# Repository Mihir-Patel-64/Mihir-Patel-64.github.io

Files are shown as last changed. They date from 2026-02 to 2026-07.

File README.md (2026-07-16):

# R6 Recon Amphibot – Team XPED Documentation

This repository contains the technical documentation for the ESP32 Wireless Communication Gateway, my individual subsystem contribution to Team XPED's R6 Recon Amphibot, developed as part of EGR314 Embedded Systems Design.

The documentation covers the complete subsystem development process, including requirements definition, hardware architecture, component selection, power analysis, schematic and PCB design, firmware interfaces, API documentation, verification, and engineering reflections.

## Website

https://mihir-patel-64.github.io/

## My Responsibilities

- Designed the ESP32-S3 Wireless Communication Gateway
- Implemented the MQTT ↔ UART communication bridge
- Developed Wi-Fi connectivity and failsafe behavior
- Implemented the camera streaming infrastructure
- Designed the hardware and PCB layout
- Documented firmware architecture and APIs

## Repository Contents

- Requirements
- Hardware Architecture
- Component Selection
- Schematic and PCB Design
- Firmware API Documentation
- Verification
- Resources
- Engineering Reflection

## Technologies

- ESP32-S3
- MQTT
- UART
- KiCad
- MkDocs
- GitHub Pages
- MicroPython

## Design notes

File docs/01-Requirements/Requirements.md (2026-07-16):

---
title: Module Requirements
tags:
  - EGR314
  - Team 302
  - ESP32
  - Wireless Communication
---

# ESP32 Wireless Communication Gateway Requirements

This section defines the functional and performance requirements for the **ESP32 Wireless Communication Gateway** subsystem. The gateway enables remote robot control, MQTT communication, telemetry transmission, and safe system operation during wireless communication failures. Each requirement includes threshold and target objectives together with the final implementation outcome.

---

## Module Requirements

**Subsystem:** ESP32 Wireless Communication Gateway

**Engineer:** Mihir Patel

| Requirement Description | Threshold | Target | Stretch | Final Result |
|---|---|---|---|---|
| Surface-mounted 3.3 V switching regulator | Output ≥ 3.2 V | Stable 3.3 V output | No | **Met** — AP63203WU-7 provided a stable 3.3 V supply under full system load |
| ESP32 microcontroller operation | Successful boot | Reliable Wi-Fi and MQTT operation | No | **Met** — ESP32-S3 booted consistently and maintained reliable MQTT connectivity |
| Wireless communication | Basic one-way communication | Full two-way MQTT messaging | No | **Met** — Complete publish/subscribe MQTT communication implemented |
| UART communication with system bus | Basic TX/RX | Structured packets with CRC | No | **Met** — 64-byte UART packet protocol implemented and successfully forwarded between subsystems |
| Video data handling | Image acquisition | Stable low-latency video streaming | Yes | **Partially Met** — Camera firmware (`camera_module.py`) and laptop viewer (`viewer.py`) were fully implemented with chunked MQTT frame transmission, but live streaming was not demonstrated on the final hardware |
| Connection loss handling | Detect wireless disconnection | Automatic safe-stop behavior | Yes | **Met** — Wi-Fi failsafe implemented; emergency stop packet broadcast over UART whenever the wireless connection was lost |

---

# Requirement Review

## Successfully Implemented Requirements

The five primary subsystem requirements were successfully implemented and verified.

The **AP63203WU-7** switching regulator delivered a stable **3.3 V** output throughout testing while maintaining approximately **847.5 mA** of available current headroom beyond the calculated worst-case system load.

The **ESP32-S3-WROOM-1-N8R8** booted reliably and maintained stable Wi-Fi and MQTT connectivity throughout subsystem testing.

Two-way MQTT communication operated as intended, allowing telemetry to be published to the MQTT broker while receiving remote control commands that were forwarded across the UART daisy-chain.

The structured **64-byte UART communication protocol** was implemented according to the subsystem API specification, including packet framing, board identification, routing, and message-type handling.

The Wi-Fi connection-loss failsafe, originally identified as a stretch objective, was also fully implemented. Whenever the MQTT connection was interrupted, the firmware detected the failure and immediately broadcast an emergency stop packet (`0x0005`) across the UART network to safely halt the actuator subsystem.

---

## Stretch Goal: Video Data Handling

Video streaming was the only requirement that reached software completion without full hardware verification.

The complete software infrastructure was implemented, including:

- `camera_module.py` for OV5640 initialization, image capture, and chunked Base64 MQTT frame publishing.
- `viewer.py` for laptop-side frame reconstruction and real-time OpenCV display.
- `config_additions.py` defining the camera MQTT topics (`TOPIC_CAM_CMD`, `TOPIC_CAM_FRAME`, and `TOPIC_CAM_STATUS`).

The architecture supports:

- On-demand image capture
- Continuous video streaming
- Configurable frame rates
- Remote stream start and stop using MQTT commands

Although the software implementation was completed, live end-to-end camera streaming was not demonstrated on the final assembled hardware.

The primary limitation was the time available for complete hardware bring-up following PCB assembly. The OV5640 interface requires careful hardware verification, and the MicroPython `esp32-camera` library requires firmware compiled with camera support enabled. These final validation steps were not completed within the project timeline.

Additional discussion is provided in the **Hardware V2.0** and **Reflection** sections.

---

# Feature-to-Requirement Rationale

The ESP32 Wireless Communication Gateway is a critical subsystem because it provides the communication interface between the operator and every onboard subsystem.

Reliable wireless communication enables:

- Remote driving
- Real-time telemetry monitoring
- MQTT-based command and control
- System status reporting
- Safe operation during communication failures

These system-level responsibilities directly resulted in requirements for reliable bidirectional Wi-Fi communication, structured UART messaging, and automatic failsafe behavior.

Power-related requirements ensure stable ESP32 operation while preventing communication failures caused by voltage instability.

The video-streaming requirement originated from the Amphibot's primary reconnaissance mission, where a live FPV feed provides the operator with situational awareness during exploration.

Although this stretch objective was not fully demonstrated on hardware, it directly influenced several hardware design decisions. Most notably, it justified selecting the **ESP32-S3-WROOM-1-N8R8** instead of the N4 variant because the additional **8 MB PSRAM** is required by the OV5640 camera driver and cannot be replaced through software optimization alone.

---

# Requirement Verification Summary

| Total Requirements | Fully Met | Partially Met | Not Met |
|---:|---:|---:|---:|
| 6 | 5 | 1 | 0 |

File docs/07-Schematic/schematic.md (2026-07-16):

---
title: Schematic
tags:
- Mihir's Individual Datasheet - Schematic
---

## Schematic

This schematic shows the complete design for my Wireless Communication subsystem. It includes the ESP32-S3-WROOM-1-N8R8 microcontroller module, switching 3.3V power supply (AP63203WU-7 buck regulator), barrel jack input with fuse and reverse polarity protection, USB micro connector for programming, UART daisy-chain ribbon connectors, boot and enable circuitry, debug LEDs, and expansion headers.

The schematic demonstrates all required power regulation, signal routing, protection circuitry, and communication interfaces necessary for reliable subsystem operation and integration within the team's UART-based daisy-chain architecture.

Two schematic-specific net label conventions are worth noting: the USB differential pair is labeled USB_N (D−, GPIO19) and USB_P (D+, GPIO20) rather than the more common D+/D− naming, and the OV5640 camera module connects via J6, a 2×9 pin header whose signals are fully isolated from the UART daisy-chain connectors J4 and J7.

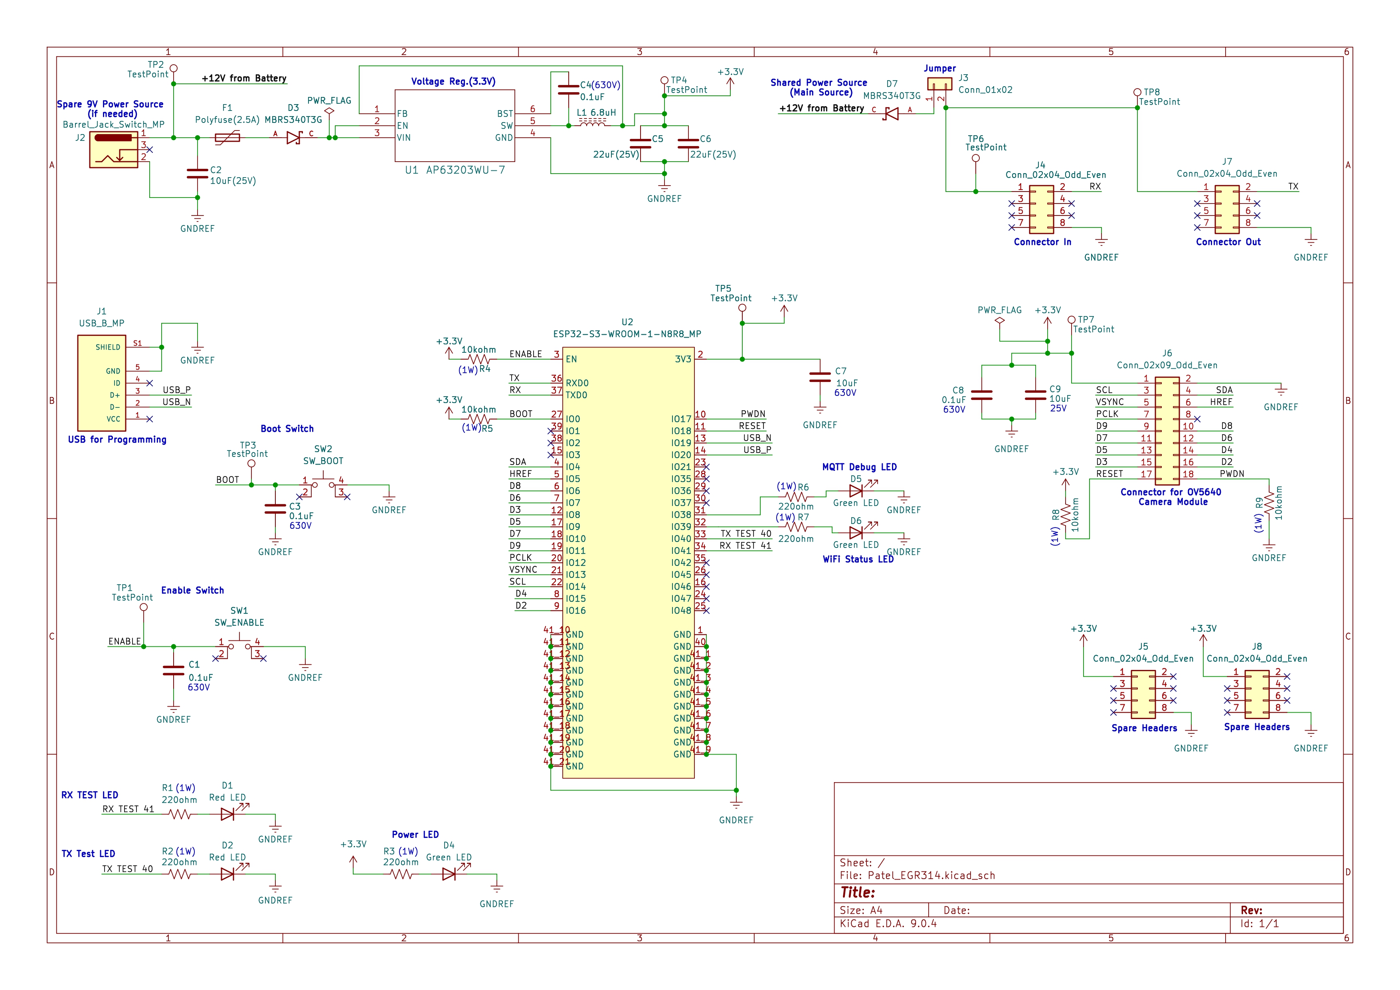
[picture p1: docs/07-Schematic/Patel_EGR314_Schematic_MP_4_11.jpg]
Wireless Communication Schematic


**Figure 01:** Wireless Communication Subsystem Schematic

---

### Supporting Files

- **Project ZIP:**  
  [Download KiCad Project ZIP](Patel_EGR314_projectzip_4_11.zip)

- **Symbol Library ZIP:**  
  [Download Symbol Library ZIP](Patel_314_symbols.zip)

- **Schematic Image:**  
  [Wireless Communication Schematic](Patel_EGR314_Schematic_MP_4_11.jpg "Wireless Communication Schematic")

- **Schematic PDF:**  
  [Download High-Resolution Schematic PDF](Patel_EGR314_Schematic_MP_4_11.pdf)

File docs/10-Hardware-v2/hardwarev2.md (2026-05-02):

---
title: Hardware V2.0
tags:
- Mihir's Individual Datasheet - Hardware V2.0
---

# Hardware V2.0

If I were to design a second version of this board, there are several things I
would change based on what I learned during bring-up, integration, and the final
demonstration.

---

## Replace Micro USB with USB-C

The Micro USB connector worked fine for programming but it feels outdated and the
connector is more fragile than USB-C. A USB-C receptacle with the correct CC
resistors would be a straightforward swap that makes the board more durable during
repeated demo handling and more compatible with modern laptops that no longer ship
with Micro USB cables. The ESP32-S3 native USB differential pair would still be
used the same way, only the physical connector would change.

## Add a Dedicated Camera Power Rail

The OV5640 camera currently shares the main 3.3V rail with the ESP32, the debug
LEDs, and everything else on the board. During camera operation the current draw
spikes significantly. In a V2 design I would add a small secondary LDO, something
like the TLV70033, specifically for the camera module. This would isolate camera
noise from the ESP32 power rail and reduce the risk of brownouts during frame
capture. It would also make it easier to power-gate the camera when it is not in
use, which would help with overall power consumption.

## Fix the Camera Connector and Verify Pin Mapping

The J6 camera connector on V1 used a 2x9 pin header with a pin mapping derived
from the schematic. The mismatch between the schematic pin assignments and the
MicroPython esp32-camera library's expected pin ordering was one of the main
reasons the camera was not demonstrated. In V2 I would verify the exact pin
mapping required by the firmware library first, then design the connector and
schematic around that, instead of the other way around. I would also add a small
silkscreen label on the PCB for each camera pin to make bring-up easier.

## Add Decoupling Capacitors Closer to the ESP32 Module

The current design has decoupling capacitors on the 3.3V rail but they are not
placed as close to the ESP32 module pads as they should be. During WiFi
transmission the ESP32 draws current in short bursts and the decoupling needs to
be right at the module to be effective. In V2 I would place 100nF and 10uF
capacitors directly adjacent to the 3V3 and GND pins of the module following the
Espressif layout recommendations more strictly.

## Switch to a Higher Current Regulator

The AP63203WU-7 at 2A worked within the power budget, but the margin between the
worst-case load and the regulator limit was comfortable but not generous. If V2
adds a dedicated camera rail and any additional peripherals, upgrading to a 3A
regulator like the AP63205WU-7 in the same SOT-23-6 package would provide more
headroom without any layout changes.

## Add an LED for Camera Status

The current board has LEDs for MQTT activity, WiFi status, UART RX, and UART TX,
but nothing specifically for camera state. In V2 I would add a fifth indicator
LED on a dedicated GPIO to show whether the camera is actively streaming. During
demos this would make it immediately obvious whether the camera stream is running
without needing to check the laptop viewer.

## Improve the Antenna Keepout Zone Compliance

The ESP32-S3-WROOM-1 module requires a keepout area under the antenna section of
the module where no copper, traces, or components should be placed. The V1 layout
followed this generally but could be improved. In V2 I would be more careful about
enforcing the keepout on all layers including inner layers and the ground plane,
following the Espressif PCB design guidelines exactly.

## Add JTAG Debug Header

The current board relies entirely on USB serial for debugging. In V2 I would add
a small JTAG header broken out from the ESP32-S3 JTAG pins. This would allow
hardware-level debugging with OpenOCD if the firmware ever gets into a state where
USB serial is not responsive, which happened a few times during bring-up when the
firmware crashed before the USB stack initialized.

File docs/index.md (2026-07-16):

---
title: Welcome
tags:
- ESP32 Wireless Communication Gateway - Welcome Page
---
<center>

<font size="6">ESP32 Wireless Communication Gateway</font><br>

**Mihir Patel**<br><br>

<font size="8">Team XPED - R6 Recon Amphibot (Amphibot V1)</font><br>

<font size="5">EGR314 Embedded Systems Design • Team 302</font>

</center>

## Introduction

This documentation presents the design and implementation of my **ESP32 Wireless Communication Gateway** for the Team XPED R6 Recon Amphibot. The gateway enables reliable wireless communication between the robot and a remote operator while integrating with the robot's modular UART-based architecture.

The documentation covers subsystem requirements, hardware architecture, component selection, firmware implementation, PCB design, communication interfaces, verification, and engineering decisions. It also explains how the subsystem integrates with the overall robotic platform and supports reliable operation during remote exploration missions.

---

## Project Overview

The **R6 Recon Amphibot** is a compact amphibious exploration robot designed for remote reconnaissance in challenging environments. The system streams live FPV video, transmits sensor telemetry, and allows an operator to remotely monitor and control the robot while evaluating environmental hazards.

The **ESP32 Wireless Communication Gateway** serves as the primary communication bridge between the robot and the operator. Its responsibilities include:

- Maintaining a reliable Wi-Fi connection with an external MQTT broker.
- Translating UART packets from the modular communication bus into MQTT topics and vice versa.
- Broadcasting a motor safe-stop command over the UART bus whenever wireless communication is lost.
- Providing the software infrastructure required for live FPV video streaming using the OV5640 camera module.
- Supporting real-time telemetry, command routing, and remote system monitoring.

The gateway provides the communication backbone that enables remote operation and coordination between every subsystem in the Amphibot.

For additional system-level documentation, visit the **Team XPED Project Website**:

**https://egr314-s-2026-302.github.io/EGR314-Team302.github.io/**

---

## My Contributions

I was responsible for the design and implementation of the **ESP32 Wireless Communication Gateway** subsystem.

My responsibilities included:

### Hardware Design

- Designed the subsystem around the **ESP32-S3-WROOM-1-N8R8** microcontroller.
- Selected and integrated the **AP63203WU-7** 3.3 V switching regulator.
- Designed the barrel-jack power input and power-jumper circuitry.
- Integrated the **2×4 IDC ribbon connector** for the modular UART communication bus.

### Firmware Development

- Implemented Wi-Fi connectivity and MQTT communication using the **mqtt_as** asynchronous library.
- Developed the MQTT-to-UART communication bridge.
- Implemented automatic reconnection logic and Wi-Fi loss failsafe behavior.
- Developed UART packet routing and subsystem message handling.

### Camera Infrastructure

- Developed `camera_module.py` for OV5640 image capture and MQTT-based frame transmission.
- Developed `viewer.py` for frame reconstruction and live image display on the operator's computer.

### System Integration

- Designed the 64-byte UART communication protocol.
- Implemented board identification and packet routing across the UART daisy-chain.
- Integrated the wireless gateway with the complete Team XPED communication architecture.

### Documentation

- Produced subsystem requirements.
- Created hardware block diagrams.
- Documented component selection decisions.
- Developed schematic and PCB documentation.
- Documented firmware APIs and communication interfaces.
- Performed subsystem verification and validation.

---

## Documentation Overview

The following sections describe each stage of the subsystem design and implementation.

| Section | Description |
|---|---|
| **[Requirements](01-Requirements/Requirements.md)** | Functional and performance requirements, design objectives, and verification results. |
| **[Block Diagram](02-Block-Diagram/Block-Diagram.md)** | Hardware architecture showing power domains, UART interfaces, ESP32 peripherals, and external connections. |
| **[Component Selection](03-Component-Selection/Component-Selection.md)** | Component evaluation and selection rationale for the wireless communication subsystem. |
| **[Microcontroller Selection](04-Microcontroller-Selection/Microcontroller-Selection.md)** | Comparison of candidate microcontrollers and justification for selecting the ESP32-S3. |
| **[Power Budget](05-Power-Budget/Power-Budget.md)** | Power consumption analysis, regulator selection, and power distribution. |
| **[Bill of Materials](06-BOM/BOM.md)** | Complete list of components, manufacturers, footprints, quantities, and estimated costs. |
| **[Schematic](07-Schematic/schematic.md)** | Electrical schematic of the ESP32 Wireless Communication Gateway. |
| **[PCB Layout](08-PCB/pcb.md)** | PCB layout, routing decisions, and hardware design considerations. |
| **[API Documentation](09-API/api.md)** | UART protocol, MQTT topics, firmware interfaces, and software architecture. |
| **[Hardware Revision 2.0](10-Hardware-v2/hardwarev2.md)** | Proposed improvements for a future hardware revision. |
| **[Resources](11-Resources/resources.md)** | Source code, downloadable project files, and demonstration videos. |
| **[Reflection](12-Reflection/reflection.md)** | Engineering lessons learned, design reflections, and recommendations for future development. |

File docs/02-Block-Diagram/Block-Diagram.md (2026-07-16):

---
title: Block Diagram
tags:
  - ESP32 Wireless Communication Gateway
  - Block Diagram
  - EGR314
---

## Overview

This block diagram represents the **ESP32-based Internet Two-way Wireless Communication subsystem** developed by **Mihir Patel** for **Team 302 – R6 Recon Amphibot**. The purpose of this subsystem is to act as the team's wireless gateway, enabling remote communication with the operator while coordinating data exchange between onboard subsystems through a **UART daisy-chain architecture**.

The diagram follows the **EGR314 block diagram standard** and clearly separates this individual subsystem from the rest of the system using a defined subsystem boundary. All major electrical components, communication interfaces, and power paths are shown with labeled signal directions, specific GPIO pin numbers, and voltage levels.

---

## Decision Objectives

The block diagram was structured around three guiding principles: functional isolation, signal clarity, and EGR314 compliance. The most important early decision was to separate the wireless communication path (Wi-Fi/MQTT) from the wired system communication path (UART daisy-chain) at the block level. This isolation prevents RF interference from coupling into the UART signal lines and makes each communication domain independently verifiable during bring-up.

The subsystem boundary was drawn to include only the components directly owned and operated by this module — the ESP32-S3 module, the OV5640 camera, the AP63203WU-7 regulator, the protection circuitry, and the debug hardware. The two 2×4 IDC ribbon connectors sit at the boundary edge, representing the interface points with the rest of the team's daisy-chain network. This boundary definition directly satisfies the product requirement for modular subsystem isolation: any board in the chain can be disconnected via its jumpers and tested independently without affecting other boards.

The decision to show GPIO numbers explicitly on the diagram (rather than just signal names) was made to support direct schematic cross-referencing. During integration testing, teammates needed to know exactly which physical pins carried UART TX, UART RX, and shared power, so labeling at the GPIO level rather than the peripheral level reduced ambiguity. The power jumper structure was included in the diagram because it represents an active design decision that affects how the board is powered in different test scenarios — showing it in the block diagram communicates that behavior to anyone reading the datasheet without requiring them to trace through the schematic.

The camera block is shown within the subsystem boundary because it communicates exclusively through the ESP32's internal camera interface and does not interact with any shared system bus. Placing it inside the boundary reflects the actual hardware topology and satisfies the product requirement for wireless video transmission without adding complexity to the inter-board protocol.

---

## Functional Overview

The ESP32 Wireless Gateway performs three primary functions within the overall exploration device:

### 1. Two-Way Wireless Communication

The ESP32 connects to an external **MQTT Server** over Wi-Fi.

- Telemetry, system status, and debug information are published to **`PUBLISH_TOPIC`**
- Incoming control commands are received through **`SUBSCRIBE_TOPIC`**

This satisfies the EGR314 team requirement for **bidirectional wireless communication using MQTT**.

---

### 2. UART Daisy-Chain System Interface

The ESP32 interfaces with neighboring subsystems through a standardized **UART daisy-chain**:

- **RX → GPIO44**
- **TX → GPIO43**

Signals are routed through:

- **Upstream Connector In** (2×4 IDC, 8-pin)
- **Downstream Connector Out** (2×4 IDC, 8-pin)

This architecture allows structured messages to pass safely across all boards in the team's daisy-chain network while maintaining modular isolation between subsystems.

---

### 3. Local Debug and Status Indication

Multiple GPIO-driven debug LEDs provide real-time visual feedback during operation:

| LED | GPIO | Purpose |
|-----|---|---|
| Power LED | 3.3V Rail | Indicates onboard 3.3V power is active |
| MQTT Debug LED 1 | GPIO38 | MQTT publish activity indicator |
| MQTT Debug LED 2 | GPIO39 | MQTT subscribe activity indicator |
| RX Debug LED | GPIO40 | UART receive signal indicator |
| TX Debug LED | GPIO41 | UART transmit signal indicator |

These indicators assist with:

- Hardware bring-up  
- Power confirmation  
- UART signal verification  
- Demonstration clarity during lab testing and the Innovation Showcase  

---

## Power Architecture

Power is supplied through an external:

**WSU090-2500 9V 2.5A AC-DC wall adapter**

The adapter connects via a **DC barrel jack**, feeding an onboard:

**AP63203WU-7 3.3V switching regulator**

The regulator provides regulated 3.3V power to:

- ESP32-S3-WROOM-1-N8R8 module  
- Adafruit OV5640 camera module  
- Debug LEDs  
- GPIO headers  
- UART daisy-chain connectors  

### Power Source Selection

Two jumpers are placed directly before the regulator input to allow selectable power sourcing:

1. **9V Supply → Regulator Input**  
   Allows the onboard 9V barrel jack supply to power the regulator.

2. **Jumper 1 — Shared Bus Power (from IDC connector) → Regulator Input**  
   Allows the shared system power rail from the 2×4 IDC connector to power the regulator.

Only one source should be connected at a time. These jumpers allow the subsystem to:

- Be powered independently from its own 9V adapter  
- Be powered from the team's shared bus  
- Be safely isolated during debugging and verification  

This configuration fully satisfies the EGR314 requirement for jumper-controlled power path selection and subsystem isolation.

---

## Programming Interface

The ESP32-S3 is programmed using its **native USB interface**:

- **USB_N (USB D−) → GPIO19**
- **USB_P (USB D+) → GPIO20**

These net labels (USB_N and USB_P) are used in the schematic and correspond directly to the ESP32-S3's native USB differential pair pins. These signals connect to an onboard **Micro USB connector**, enabling:

- Direct firmware flashing  
- Serial monitoring  
- No external USB-to-UART bridge chip required  

Two tactile switches support standard ESP32 boot operation:

- **SW1 — BOOT Pin**: Forces download mode for firmware upload  
- **SW2 — EN Pin**: Manually resets the ESP32  

The USB interface is intentionally kept separate from the UART daisy-chain bus to prevent signal interference.

---

## Camera Interface

An **Adafruit OV5640 camera module** (5MP, DVP interface) is included within the subsystem boundary.

- Communicates internally using the ESP32's native parallel camera interface (DVP)  
- Does **not** share UART, SPI, or I²C system buses  
- Streams JPEG frames wirelessly over Wi-Fi via chunked MQTT messages  

This enables live reconnaissance capability without interfering with inter-board UART communication. The camera interface uses a dedicated 2×9 pin header (J6) on the PCB, keeping camera signals fully isolated from the daisy-chain connectors.

---

## Standards Compliance

This block diagram satisfies EGR314 requirements by:

- Clearly identifying the **individual subsystem boundary**
- Showing all utilized ESP32 peripherals (UART, GPIO, USB, Wi-Fi, Camera)
- Labeling **signal directions, GPIO numbers, and voltage levels**
- Including both **upstream and downstream 2×4 IDC connectors**
- Separating wireless networking from wired system communication
- Supporting modular verification and subsystem isolation

By isolating wireless communication and system coordination within the ESP32 gateway, the design improves reliability, scalability, and ease of debugging.

---

## Block Diagram

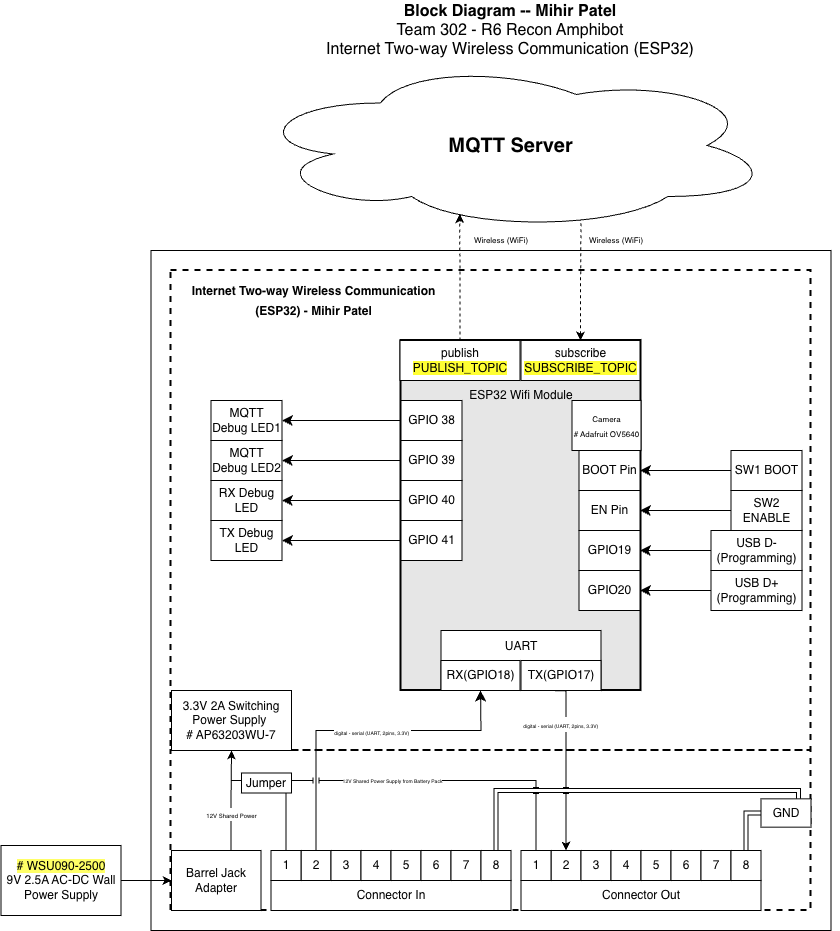
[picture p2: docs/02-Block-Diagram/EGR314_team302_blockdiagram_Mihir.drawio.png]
ESP32 Wireless Gateway Block Diagram


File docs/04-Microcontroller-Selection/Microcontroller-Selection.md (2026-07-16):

---
title: Microcontroller Selection
tags:
  - ESP32 Wireless Communication Gateway
  - Microcontroller Selection
  - ESP32-S3
---

# ESP32 Wireless Communication Gateway Microcontroller Selection

### Microcontrollers Considered

**Choice A — ESP32-S3-WROOM-1-N8R8 (selected)**  
- **Link / Datasheet:** [Datasheet](https://documentation.espressif.com/esp32-s3-wroom-1_wroom-1u_datasheet_en.pdf)
- **Type:** Surface-mount module (SMD) with integrated antenna, 8MB flash, 8MB PSRAM  
- **Pros:** Integrated Wi-Fi/BLE, native USB support, 8MB PSRAM enables OV5640 camera frame buffering, large GPIO count, pre-certified RF reduces layout risk, same footprint as N4 variant.  
- **Cons:** Slightly larger footprint and higher per-unit cost than bare chip; module antenna performance depends on board placement.

**Choice B — ESP32-WROOM-32 (classic module)**  
- **Link / Datasheet:** [Datasheet](https://documentation.espressif.com/esp32-wroom-32_datasheet_en.pdf)  
- **Type:** Surface-mount module, classic ESP32 (older core)  
- **Pros:** Mature ecosystem, lots of community examples, widely available dev boards for testing.  
- **Cons:** Older architecture (no native USB, less optimized camera/USB support), fewer advanced peripheral features than S3; less headroom for camera streaming.

**Choice C — ESP32-S3 (bare QFN chip)**  
- **Link / Datasheet:** [Datasheet](https://documentation.espressif.com/esp32-s3_datasheet_en.pdf)  
- **Type:** Bare QFN package (lowest cost per unit)  
- **Pros:** Smallest PCB footprint, lowest BOM cost (chip only), maximum control over RF layout and BOM.  
- **Cons:** Requires custom RF layout and impedance matching (high risk for first spin), more difficult assembly (QFN), needs certified antenna or careful trace design.

**Selection Rationale (summary):** The ESP32-S3-WROOM-1-N8R8 (Choice A) gives the best tradeoff of RF reliability, native camera and USB support, 8MB PSRAM for OV5640 frame buffering, and quick bring-up for the wireless gateway role. Choice B lacks PSRAM entirely and cannot support the OV5640 camera at any useful resolution. Choice C is lowest cost but introduces RF design risk unacceptable for a first hardware revision.

---

## 2. Selected Device

### ESP32-S3-WROOM-1-N8R8

- 41-pin surface-mount module
- Dual-core Xtensa LX7 processor
- Integrated Wi-Fi + BLE
- 8MB flash + 8MB PSRAM
- Native USB support (GPIO19/20)
- Integrated PCB antenna
- 3.3V operating voltage
- Same PCB footprint as N4 variant — drop-in replacement

---

The module pin layout and definitions are shown in:

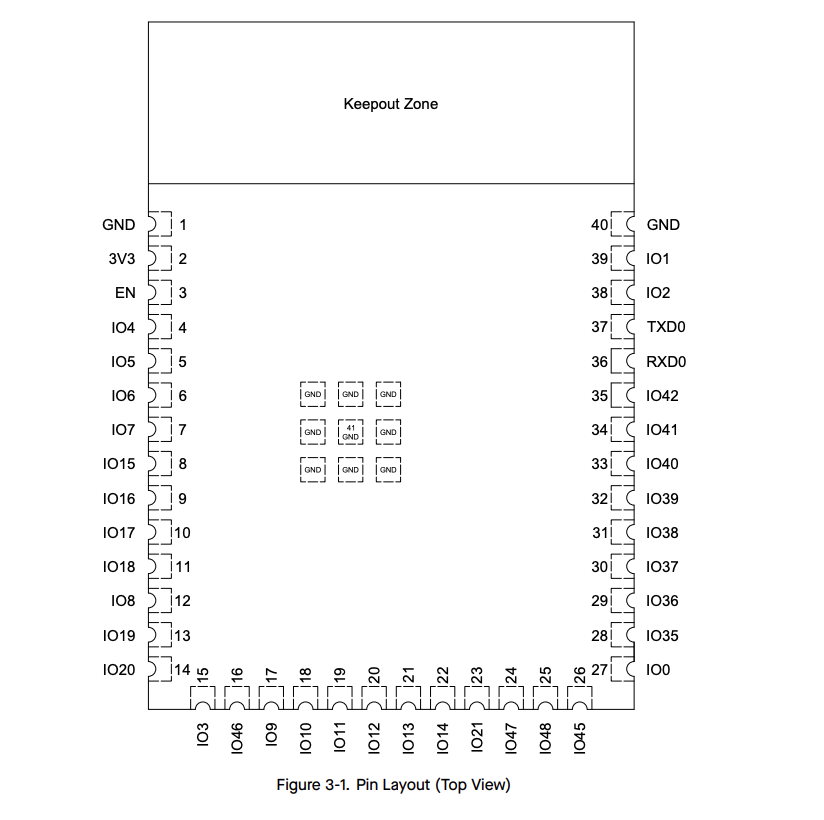
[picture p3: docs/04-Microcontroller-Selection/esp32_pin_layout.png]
ESP32-S3-WROOM-1-N8R8 Pin Layout (Top View)


**Figure 01:** ESP32-S3-WROOM-1-N8R8 Module Pin Layout (Top View) (Figure 3.1)

---

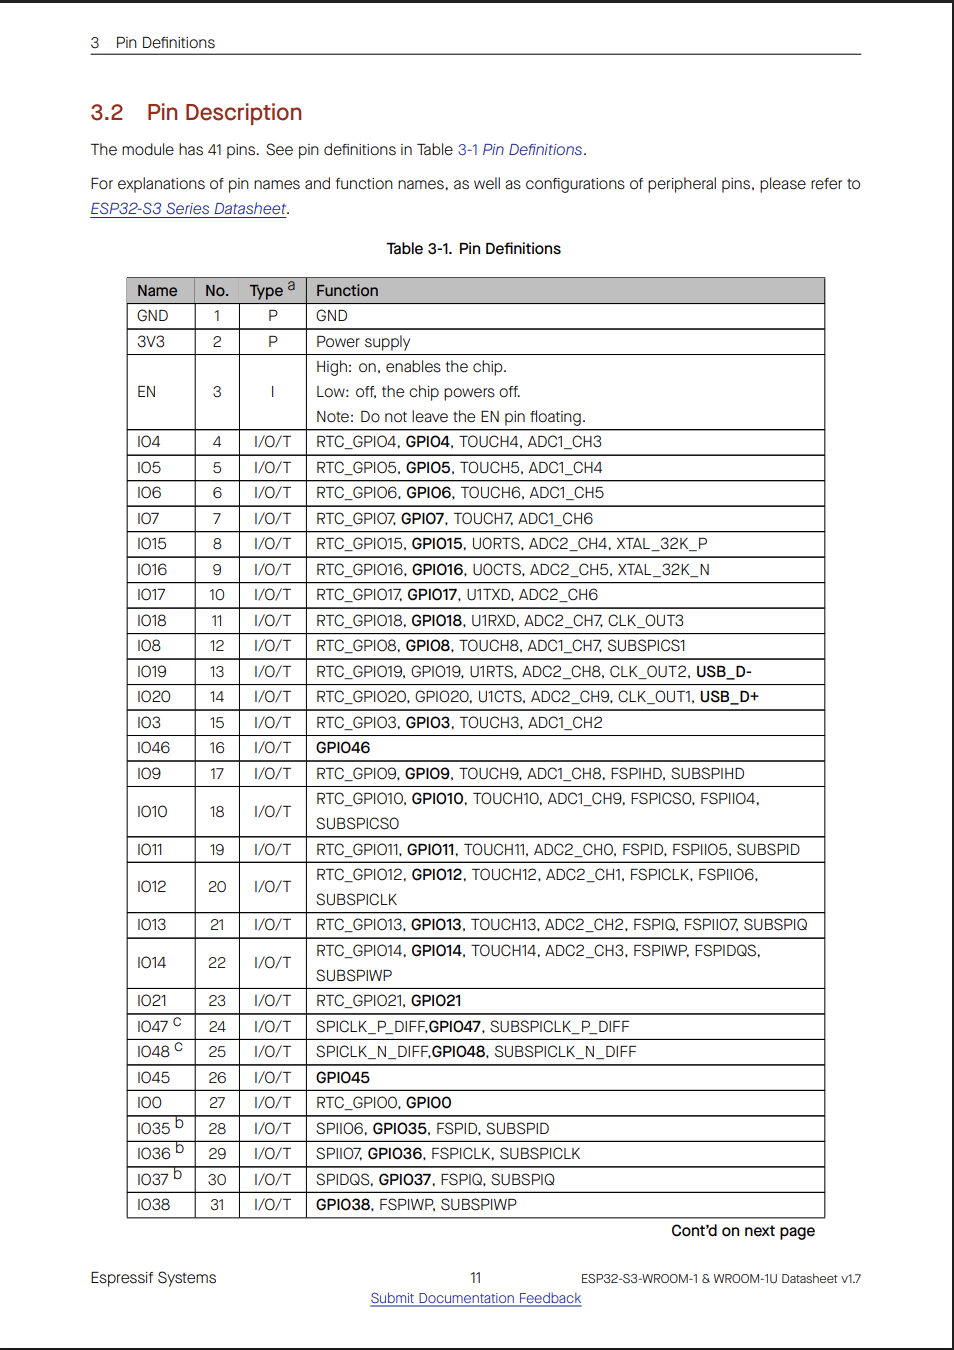
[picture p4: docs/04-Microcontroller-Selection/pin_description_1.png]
ESP32-S3-WROOM-1-N8R8 Pin Definitions Table


**Figure 02:** ESP32-S3-WROOM-1-N8R8 - Pin Definitions (Table 3-1, Part 1)

---

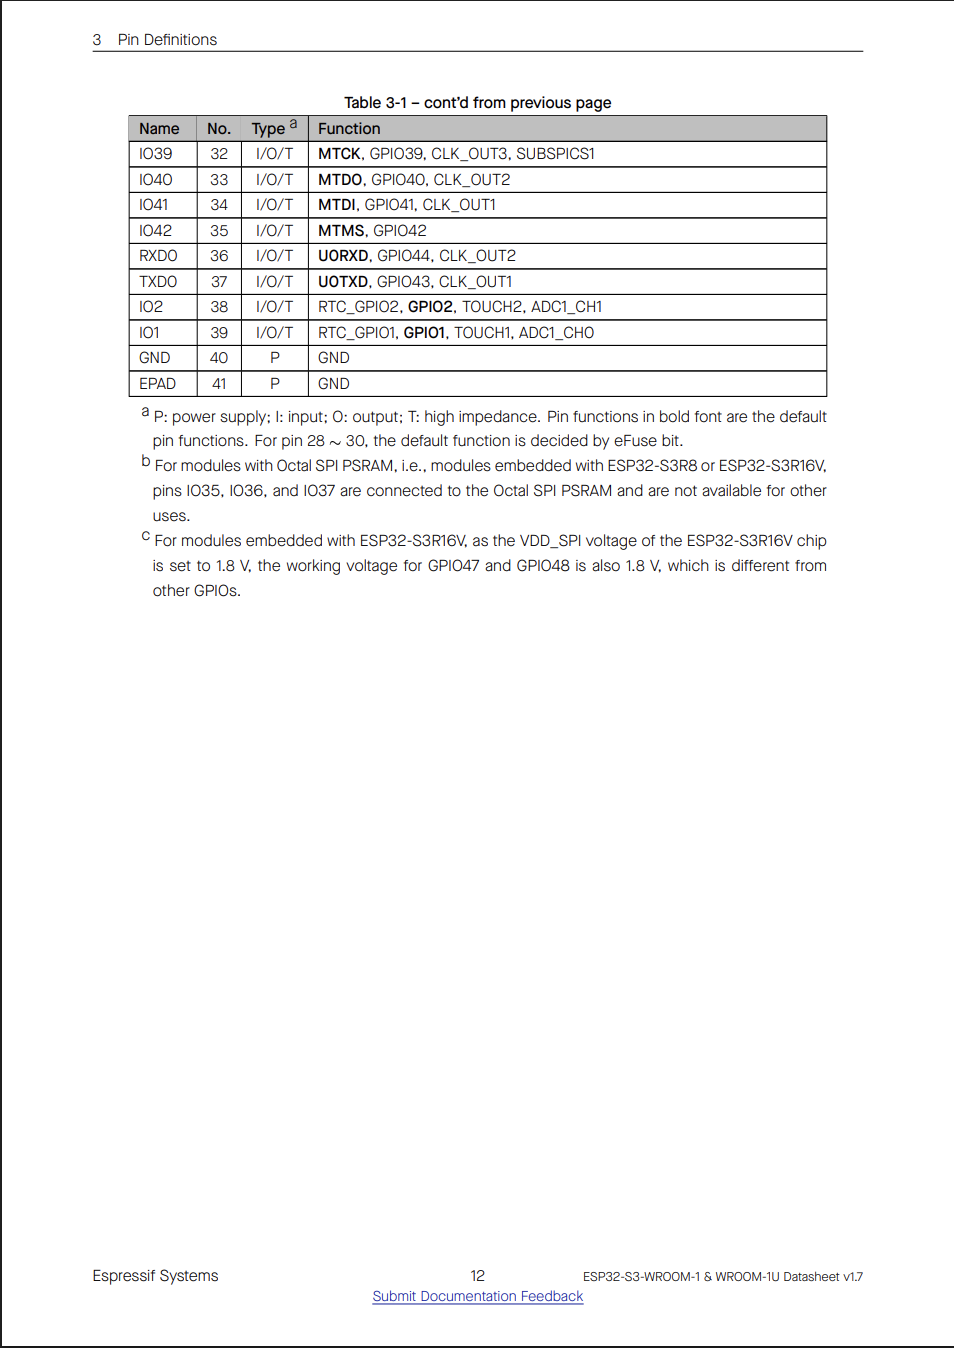
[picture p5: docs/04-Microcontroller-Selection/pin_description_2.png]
ESP32-S3-WROOM-1-N8R8 Pin Definitions Table (Continued)


**Figure 03:** ESP32-S3-WROOM-1-N8R8 - Pin Definitions (Table 3-1, Part 2)

These confirm:
- 3V3 = Pin 2  
- GND = Pins 1 and 40  
- EPAD = Ground  
- RXD0 = Pin 36 (GPIO44)  
- TXD0 = Pin 37 (GPIO43)  
- USB_D- = GPIO19 (Pin 13)  
- USB_D+ = GPIO20 (Pin 14)

---

## 3. Required Peripherals

### For the wireless subsystem, the required peripherals are:

| Peripheral | Required | Quantity |
|---|---|---|
| UART | Yes | 1 (RX + TX) |
| Wi-Fi | Yes | Integrated |
| Camera Interface | Yes | 1 (OV5640) |
| USB | Yes | 1 |
| GPIO | Yes | 4 Debug LEDs + 1 Power LED |
| PSRAM | Yes | 8MB (OV5640 frame buffers) |
| SPI | No | 0 |
| I2C | No | 0 |
| ADC | No | 0 |
| DAC | No | 0 |
| PWM | Optional | 1 |

**Estimated required GPIO count: ~20–22 (includes 8 camera data lines + 6 camera control/sync signals + UART + USB + LEDs)**

---

## 4. Microcontroller Capability Comparison

| Feature | PIC18F47Q10 | ESP32-S3-WROOM-1-N8R8 | Required? | Result |
|---|---|---|---|---|
| 32-bit CPU | No (8-bit) | Yes | Preferred | ESP32 |
| Wi-Fi | No | Yes | Required | ESP32 |
| UART | Yes | Yes (3) | ≥1 | Both |
| Camera Support (DVP) | No | Yes | Required | ESP32 |
| USB Native | Limited | Yes | Preferred | ESP32 |
| PSRAM | No | Yes (8MB) | Required for OV5640 | ESP32 |
| GPIO Count | ~36 | ~36 | ≥20 | Both |
| Flash | Limited | 8MB | ≥2MB | ESP32 |

### Evaluation

The PIC18F47Q10 does not support Wi-Fi, camera streaming, or PSRAM without significant additional hardware. The ESP32-S3-WROOM-1-N8R8 directly satisfies all wireless, streaming, and memory requirements. No critical requirements are unmet by the ESP32.

---

## 5. Pin Allocation Table (Verified Against Datasheet and Firmware)

| Function | Module | Pin | GPIO | Notes |
|---|---|---|---|---|
| 3.3V | Power | Pin 2 | 3V3 | |
| GND | Ground | Pins 1, 40 | GND | |
| EPAD | Ground | Center Pad | GND | Exposed pad |
| EN | | Pin 3 | EN | Enable |
| UART TX | | Pin 37 | GPIO43 | Daisy-chain TX |
| UART RX | | Pin 36 | GPIO44 | Daisy-chain RX |
| USB D− | | Pin 13 | GPIO19 | Native USB programming (USB_N in schematic) |
| USB D+ | | Pin 14 | GPIO20 | Native USB programming (USB_P in schematic) |
| MQTT LED | | Pin 29 | GPIO36 | MQTT activity indicator |
| WiFi LED | | Pin 28 | GPIO35 | WiFi connected/disconnected indicator |
| RX LED | | Pin 34 | GPIO41 | UART RX indicator |
| TX LED | | Pin 33 | GPIO40 | UART TX indicator |
| Camera SIOD/SDA | | Pin 4 | GPIO4 | OV5640 SCCB data |
| Camera SIOC/SCL | | Pin 22 | GPIO14 | OV5640 SCCB clock |
| Camera VSYNC | | Pin 21 | GPIO13 | Frame sync |
| Camera HREF | | Pin 5 | GPIO5 | Line valid |
| Camera PCLK | | Pin 20 | GPIO12 | Pixel clock |
| Camera D2 | | Pin 9 | GPIO16 | Data bit 2 (LSB) |
| Camera D3 | | Pin 12 | GPIO8 | Data bit 3 |
| Camera D4 | | Pin 8 | GPIO15 | Data bit 4 |
| Camera D5 | | Pin 17 | GPIO9 | Data bit 5 |
| Camera D6 | | Pin 7 | GPIO7 | Data bit 6 |
| Camera D7 | | Pin 18 | GPIO10 | Data bit 7 |
| Camera D8 | | Pin 6 | GPIO6 | Data bit 8 |
| Camera D9 | | Pin 19 | GPIO11 | Data bit 9 (MSB) |
| Camera RESET | | Pin 11 | GPIO18 | OV5640 reset |
| Camera PWDN | | Pin 10 | GPIO17 | OV5640 power down |

### Pin Sufficiency Check

Total pins required ≈ 26  
Total available GPIO ≈ 36+  

There are no pin conflicts. All camera GPIOs (4, 5, 6, 7, 8, 9, 10, 11, 12, 13, 14, 15, 16, 17, 18) are fully clear of UART (GPIO43/44), USB (GPIO19/20), and debug LED (GPIO35–36, GPIO40–41) assignments.

---

## 6. Role Description

The ESP32 Wireless Communication Gateway serves as the interface between the robot's UART daisy-chain and the external MQTT server. The subsystem manages publish/subscribe messaging, packet forwarding, debug status indication, and camera communication while maintaining modular separation from the remaining robot subsystems.

---

## 7. Software Compatibility

### Wi-Fi & MQTT
- Fully supported in MicroPython using the `mqtt_as` async library.
- Stable networking stack with automatic reconnection handling via `wifi_coro` callback.
- WiFi connection loss triggers an emergency stop broadcast over UART as a hardware failsafe.

### OV5640 Camera
- OV5640 driver requires MicroPython firmware compiled with `esp32-camera` support enabled.
- Requires 8MB PSRAM for frame buffers, satisfied by N8R8 variant.
- Adafruit OV5640 breakout (5841) has onboard oscillator, no XCLK circuit needed on host PCB.
- Camera commands (`capture`, `stream on`, `stream off`) are handled via both MQTT subscription and UART button events.

### UART
- Hardware UART2 used at 9600 baud, TX on GPIO43, RX on GPIO44.
- 64-byte structured packet format with `AZ`/`YB` header/footer framing.
- Rate-limited transmission with 500ms minimum interval between packets.

### Known Considerations
- Wi-Fi transmission causes current spikes, handled by AP63203WU-7 2A regulator with adequate headroom.
- OV5640 at VGA resolution uses ~500KB per frame, PSRAM handles this comfortably.
- PSRAM draws ~5mA additional current, negligible impact on power budget.
- Proper decoupling on camera connector 3.3V supply required (10µF + 100nF).
- MicroPython `esp32-camera` module requires custom firmware build — not available in standard MicroPython releases.

No major compatibility conflicts were identified.

---

## 8. Final Selection

**Final Choice: ESP32-S3-WROOM-1-N8R8**

### Data-Driven Rationale

- Only microcontroller variant that directly meets Wi-Fi, camera, and PSRAM requirements simultaneously.
- 8MB PSRAM is essential for OV5640 frame buffering; N4 variant cannot support this camera.
- Integrated antenna reduces RF layout risk on first revision PCB.
- Native USB simplifies firmware flashing without a separate USB-UART bridge chip.
- Satisfies surface-mount requirement with same footprint as N4, no PCB layout changes needed.
- Exceeds GPIO and UART requirements with room to spare.
- Strong MicroPython and ESP-IDF ecosystem support lowers development and debugging risk.
- ~$1.07 cost increase over N4 is justified by the full camera streaming capability gained.

The ESP32-S3-WROOM-1-N8R8 is therefore the optimal and necessary microcontroller for this subsystem.

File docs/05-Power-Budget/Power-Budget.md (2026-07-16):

---
title: Power Budget
tags:
  - ESP32 Wireless Communication Gateway
  - Power Budget
  - Hardware Design
---

# ESP32 Wireless Communication Gateway Power Budget

## Overview

This section presents the power budget for the **ESP32 Wireless Communication Gateway**, verifying that the selected voltage rail, regulator, and external power sources can reliably supply the total current required by every major active component in the subsystem.

The power budget covers:

- Peak current requirements of all major active components on the +3.3V rail
- Assigned voltage rail and total current consumption with a 25% safety margin
- Regulator selection verification confirming adequate current headroom
- External power source selection confirming the supply can drive all regulators simultaneously

This subsystem operates entirely from a single regulated +3.3V rail. The +3.3V rail can be sourced from either a 9V AC-DC wall adapter or the team's shared 12V battery, both feeding the onboard AP63203WU-7 switching buck regulator through protection diodes.

---

## Power Budget Table

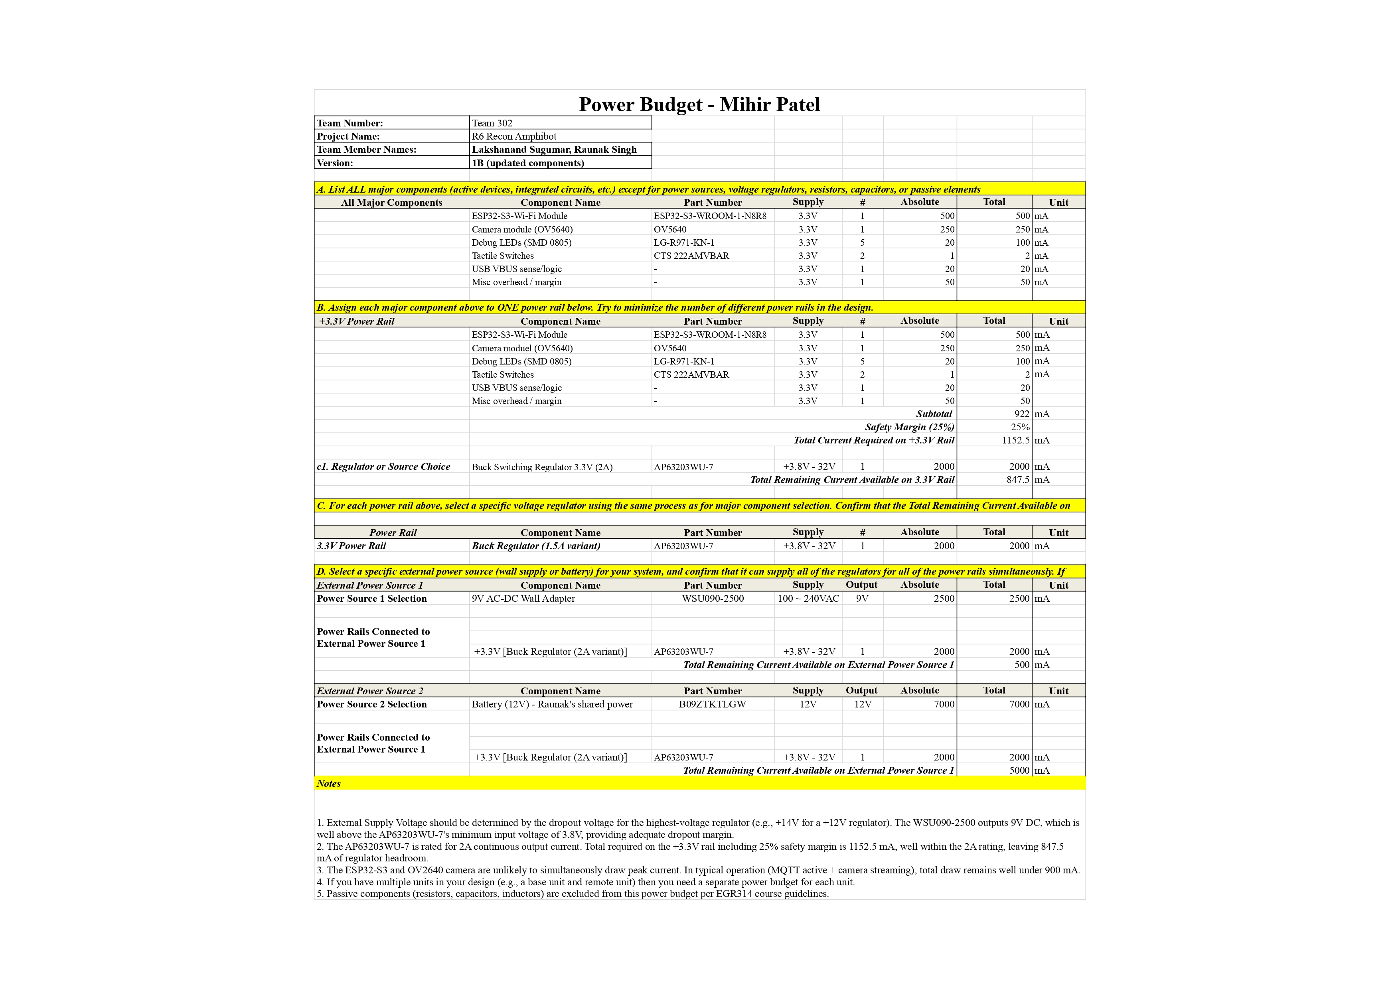
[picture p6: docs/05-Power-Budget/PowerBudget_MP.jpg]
Power Budget Table


**Figure 01:** ESP32 Wireless Communication Subsystem — Full Power Budget (Team 302, Version 1B)

---

### How the Power Budget Informed Design Choices

- The power analysis determined the worst-case current draw of all major active components on the +3.3V rail. This includes the ESP32-S3-WROOM-1-N8R8 Wi-Fi module, OV5640 camera module, five debug LEDs, two tactile switches, USB VBUS sense logic, and a miscellaneous overhead margin. Summing each device's peak current gives a subtotal of 922 mA, and applying the required 25% safety margin brings the total current required on the +3.3V rail to 1152.5 mA.

- The calculated current requirement directly guided the regulator selection. The AP63203WU-7 synchronous buck regulator, rated for 2A continuous output, was selected to provide adequate overhead above the 1152.5 mA requirement. With 847.5 mA of headroom remaining, the regulator comfortably handles Wi-Fi transmission spikes and simultaneous camera streaming without approaching its current limit.

- The same analysis was used to verify both external power sources. The primary standalone source is the WSU090-2500 9V AC-DC wall adapter, rated at 2500 mA. The secondary source is the shared 12V system battery (B09ZTKTLGW), rated at 7000 mA. Both sources feed the AP63203WU-7 through onboard protection diodes (MBRS340T3G), and either source alone is sufficient to power the entire +3.3V rail. With the 9V adapter, 500 mA of headroom remains on the supply after accounting for the regulator's maximum draw. With the 12V battery, 5000 mA of headroom remains.

- The key conclusion from this analysis is that a single +3.3V regulated rail, supplied by either the 9V wall adapter or the 12V shared battery through the AP63203WU-7, is sufficient for all wireless, camera, and communication functions in this subsystem. No additional voltage rails are required.

---

### Supporting Files

- **Power Budget EXCEL:**  
[Download Power Budget (Excel)](PowerBudget_MP.xlsx)

- **Power Budget ZIP:**  
[Download Power Budget (ZIP)](PowerBudget_MP.xlsx.zip)

- **Power Budget PDF:**  
[Download Power Budget (PDF)](PowerBudget_MP.pdf)

---

## Power Rails and Regulators

| **Power Rail** | **Regulator / Source** | **Part Number** | **Output Voltage** | **Max Current (mA)** | **Notes** |
|---|---|---|---|---|---|
| +3.3V | Synchronous Buck Regulator (2A) | AP63203WU-7 | +3.3V fixed | 2000 | Powers ESP32, camera, LEDs, switches, USB logic |

> All major components are powered from a single +3.3V regulated supply. This simplifies power distribution, reduces conversion losses, and improves overall system stability.

---

## Power Source Verification

| **Power Source** | **Part Number** | **Output** | **Max Current (mA)** | **Regulator Supplied** | **Remaining (mA)** |
|---|---|---|---|---|---|
| 9V AC-DC Wall Adapter | WSU090-2500 | 9V DC | 2500 | +3.3V [AP63203WU-7] | 500 |
| 12V Battery (Shared Team Source) | B09ZTKTLGW | 12V DC | 7000 | +3.3V [AP63203WU-7] | 5000 |

> The WSU090-2500 9V wall adapter is the primary standalone power source. It feeds the AP63203WU-7 buck regulator through an onboard protection diode (MBRS340T3G, ~0.45V drop), delivering approximately 8.55V to the regulator input, well above the 3.8V minimum. The 9V adapter alone is fully sufficient to regulate down to 3.3V for all components on the board.

> The 12V battery is the shared power source. It also connects to the same AP63203WU-7 through a protection diode, and can serve as an alternative or simultaneous supply. Either source alone is sufficient, both are within the regulator's 3.8V–32V input range.

---

### Power Budget Summary

This power budget accounts for the electrical demands of all active components in the **ESP32 Wireless Communication Gateway**, assigning each to a single regulated +3.3V power rail. Current estimates are based on worst-case peak consumption with a 25% safety margin applied.

The selected AP63203WU-7 regulator (2A variant, 2000 mA rated) exceeds the required 1152.5 mA with 847.5 mA of regulator headroom. Two external power sources are verified: the WSU090-2500 9V wall adapter (500 mA headroom) and the shared 12V team battery (5000 mA headroom). Both margins are positive, and either source alone is sufficient to drive the regulator.

No additional regulated voltage rails are required. The selected single-rail architecture simplifies power distribution while maintaining sufficient electrical headroom for continuous Wi-Fi operation, MQTT communication, and future OV5640 camera streaming.

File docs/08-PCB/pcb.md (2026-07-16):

---
title: PCB Design
tags:
- Mihir's Individual Datasheet - PCB Design
---

## PCB Design

This page contains all design files and documentation for the ESP32 Wireless 
Communication Subsystem, including the PCB layout. The system integrates an 
ESP32-S3-WROOM-1-N8R8 Wi-Fi module, OV5640 camera module, AP63203WU-7 buck 
regulator, debug LEDs, tactile switches, and supporting circuitry for wireless 
communication and image capture.

---

## ECAD Layer Views

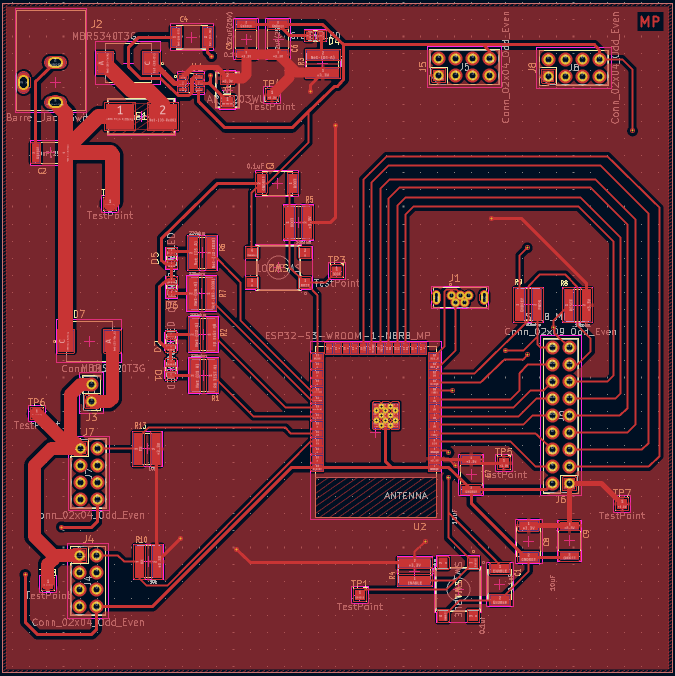
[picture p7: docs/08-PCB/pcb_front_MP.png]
Wireless Communication PCB Top Layer Image


**Figure 01:** PCB Top Layer View (ECAD)

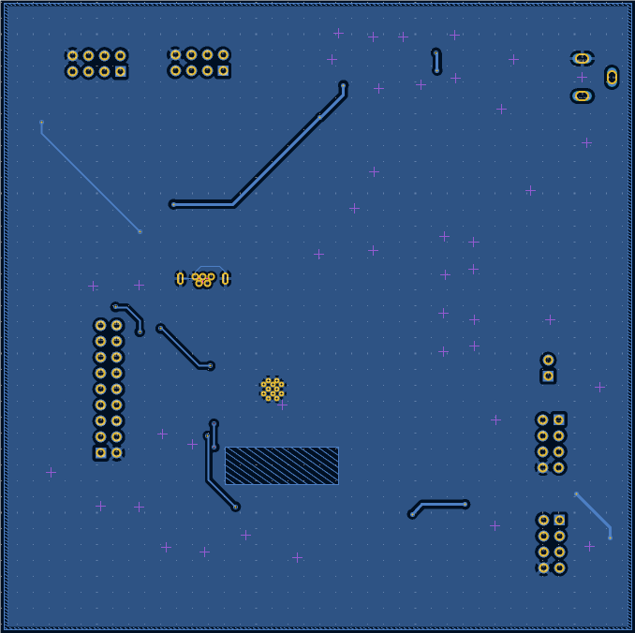
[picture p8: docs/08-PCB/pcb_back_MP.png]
Wireless Communication PCB Bottom Layer Image


**Figure 02:** PCB Bottom Layer View (ECAD)

---

## Physical PCB Photos

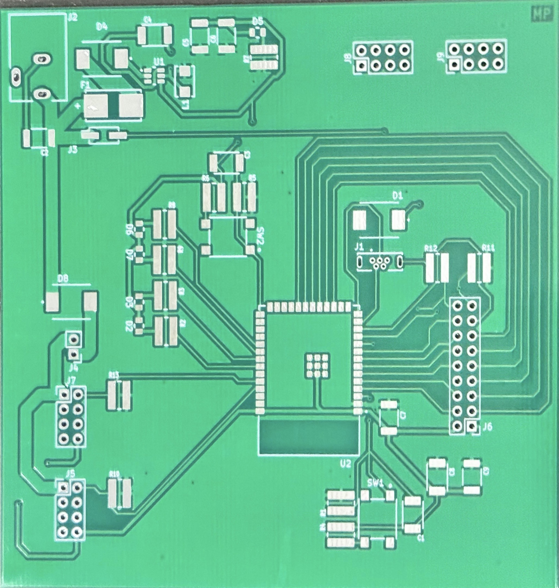
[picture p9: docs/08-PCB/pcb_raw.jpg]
Raw PCB Before Population


**Figure 03:** Raw PCB Before Population (before soldering)

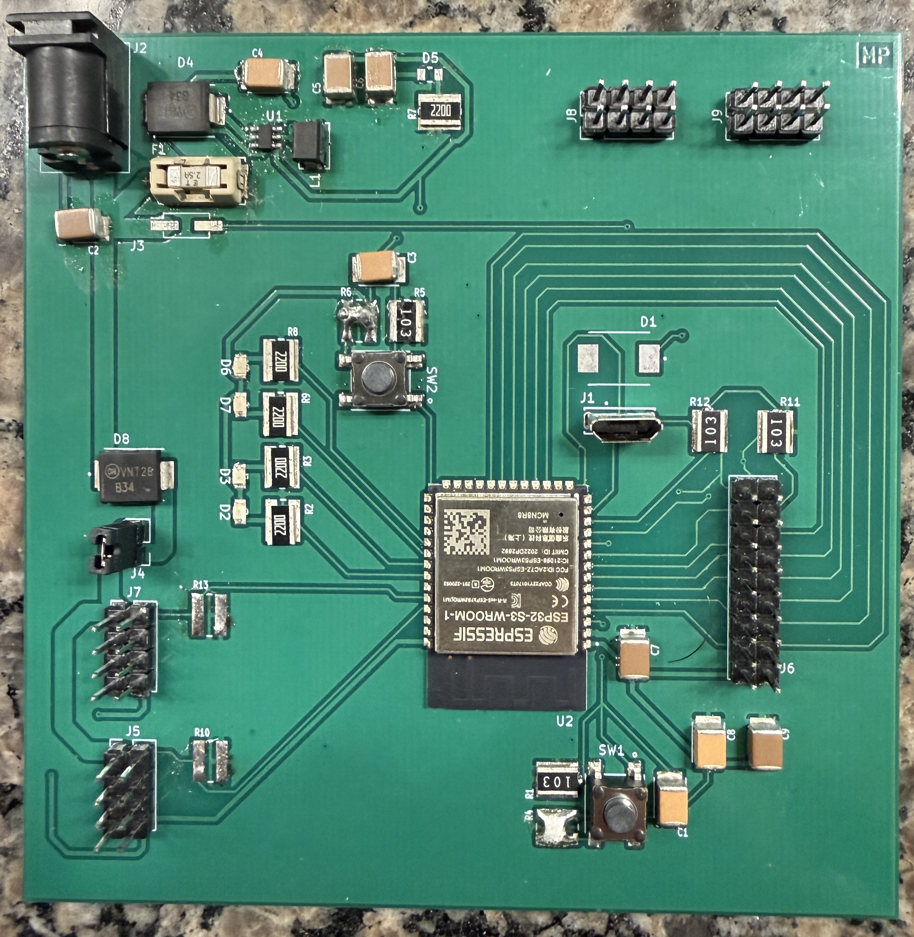
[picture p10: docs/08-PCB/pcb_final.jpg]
Finalized PCB After Soldering and Testing


**Figure 04:** Finalized PCB After Soldering and Testing

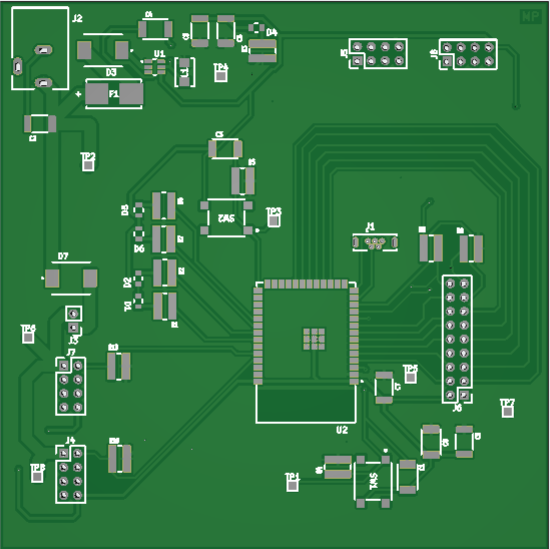
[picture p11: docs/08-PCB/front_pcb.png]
Wireless Communication Front PCB Image


**Figure 05:** PCB Front View (populated)

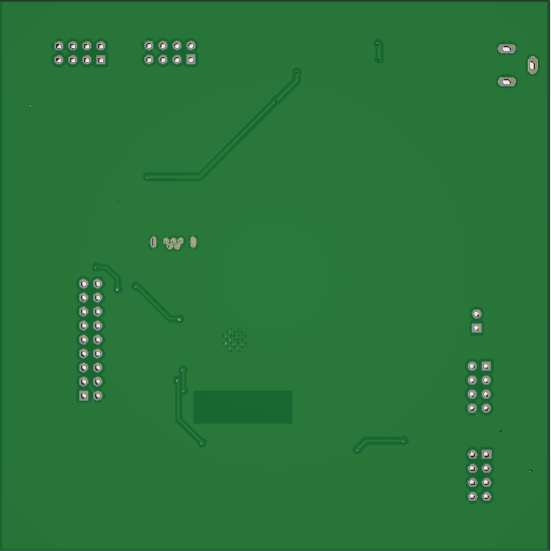
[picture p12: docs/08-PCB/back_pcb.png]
Wireless Communication Back PCB Image


**Figure 06:** PCB Back View (populated)

---

### Supporting Files

- **Project ZIP:**  
  [Download KiCad Project ZIP](Patel_EGR314_projectzip_4_11.zip)

- **PCB Gerber Files ZIP:**  
  [Download PCB Gerber Files ZIP](Gerber_drill_4_10_26.zip)

- **PCB Footprints Library ZIP:**  
  [Download PCB Footprints Library ZIP](pcb_footprints.pretty.zip)

- **PCB PDF:**  
  [Wireless Communication PCB PDF](pcb_MP.pdf)

- **PCB Top Layer Image:**  
  [Wireless Communication PCB Top Layer Image](pcb_front_MP.png)

- **PCB Top Layer PDF:**  
  [Wireless Communication PCB Top Layer PDF](pcb_front_MP.pdf)

- **PCB Bottom Layer Image:**  
  [Wireless Communication PCB Bottom Layer Image](pcb_back_MP.png)

- **PCB Bottom Layer PDF:**  
  [Wireless Communication PCB Bottom Layer PDF](pcb_back_MP.pdf)

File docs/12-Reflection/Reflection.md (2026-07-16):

---
title: Reflection
tags:
- Mihir's Individual Datasheet - Reflection
---

# Reflection

## Review of Module's Success

Looking back at the six requirements I defined for this subsystem, four core
requirements were fully met, one stretch goal was fully met, and one stretch
goal was only partially met.

The regulator worked exactly as expected. The AP63203WU-7 produced stable 3.3V
output throughout testing with plenty of headroom above the worst-case load. The
ESP32 booted reliably every session and held its MQTT connection without needing
manual resets. Two-way MQTT messaging worked end to end, telemetry received over
UART was published to the broker as JSON, and motor commands from the broker were
correctly parsed and forwarded as 64-byte UART packets to the actuator board. The
packet format was implemented as specified, with correct framing, board ID
routing, rate-limited transmission, and payload sanitization.

The WiFi failsafe stretch goal was also fully achieved. When the broker connection
dropped, the firmware detected it through the wifi callback, stopped any active
camera stream, broadcast an emergency stop packet over UART, and flashed all four
LEDs to signal the fault. This was tested and confirmed during development.

The one thing that did not get demonstrated was the camera. The full software
stack was built, camera_module.py handles OV5640 initialization and chunked MQTT
frame publishing, viewer.py reassembles and displays frames on a laptop using
OpenCV, and the three camera MQTT topics are defined in config_additions.py. The
issue was that standard MicroPython does not include the esp32-camera module. It
requires a custom firmware build with camera support compiled in, and getting that
build set up was not completed within the project timeline. The software was ready
but the hardware side of the camera bring-up was not finished in time.

---

## Microcontroller / Module Startup Tips

These are things I either found helpful, wish I had known earlier, or wish I had
followed more carefully:

1. Flash MicroPython with the right build from the start. Standard MicroPython
does not include the camera module. If your project involves the OV5640, you need
a custom firmware build before you write any camera code. Finding this out late
in the project is what caused the camera demo to be missed.

2. Test UART with a USB-to-serial adapter before connecting to teammates. Looping
back to yourself first confirms your TX and RX pins are correct and saves a lot
of confusion when things do not work in a multi-board setup.

3. The ESP32-S3 has two USB interfaces and they are not interchangeable. The
native USB on GPIO19/20 and the UART0 debug port are different. If you flash
via native USB and open a serial monitor expecting UART0 output, you will see
nothing. Make sure your flash tool and serial monitor are pointed at the same port.

4. Hold BOOT before pressing EN when entering download mode. This sounds obvious
but in a busy lab it is easy to forget. If esptool is not recognizing the chip,
this is almost always why.

5. Use mqtt_as instead of a basic MQTT library. It handles reconnection,
keep-alives, and clean sessions automatically. A blocking MQTT client will lock
up the entire firmware when the broker drops, which makes a WiFi failsafe nearly
impossible to implement.

6. Rate-limit UART transmissions. The ESP32 and PIC boards do not have the same
buffer sizes. Sending packets too fast dropped bytes on the receiving end during
early testing. The 500ms minimum interval between sends was necessary for
reliable communication.

7. Verify GPIO assignments against the actual datasheet pin table, not just the
module pin numbers. GPIO4 is not Pin 4 on the WROOM module. Cross-checking the
pin allocation table against Table 3-1 in the datasheet before routing the
schematic prevents a lot of errors.

8. Put test points on every signal you care about before ordering the PCB. They
were invaluable during bring-up. Any signal you might want to probe should have
a test point. It costs nothing in PCB area and saves significant time later.

9. The antenna keepout zone is not optional. The WROOM module has a defined
keepout area under the antenna. Placing copper there degrades RF performance.
Follow the datasheet layout guidelines exactly.

10. Start firmware development before the hardware is ready. The entire firmware
stack was developed and tested on a dev board before the custom PCB arrived. When
the PCB was assembled, there was already working firmware ready to flash. Starting
early is one of the best things you can do for your timeline.

---

## Lessons Learned

1. The gap between software-ready and hardware-verified is real. The camera
software was fully implemented but never verified on the final PCB. In embedded
systems a feature is not done until it runs on the actual target hardware.
Software completion and hardware demonstration are two different milestones and
both need time planned for them.

2. Component selection decisions have downstream consequences that are not always
obvious. Choosing the N8R8 over the N4 was a one dollar decision that made the
entire camera subsystem possible. If that choice had not been made early, the
OV5640 breakout would have been a component that could never work. Understanding
the full dependency chain before ordering parts matters a lot.

3. Async firmware architecture is worth the learning curve. Using uasyncio with
mqtt_as meant that UART polling, MQTT communication, heartbeat publishing, and
camera streaming could all run concurrently. A blocking approach would have made
the WiFi failsafe nearly impossible to implement cleanly.

4. Structured packet formats need to be agreed on and frozen early. The 64-byte
UART format worked well but there were early iterations where teammates had
different expectations. Any ambiguity in the protocol causes integration failures
that are hard to debug across boards. Lock it down in writing before anyone
starts coding.

5. Power budget analysis directly informs hardware decisions. Working through the
numbers confirmed that the AP63203WU-7 had adequate headroom for simultaneous
WiFi and camera operation. Without doing the math there would have been no way
to know if the regulator was actually sufficient.

6. PCB bring-up is its own phase of the project and needs dedicated time. Assembly,
soldering, and initial power-on each take longer than expected. The timeline needs
to budget for bring-up explicitly, not treat it as something that happens
automatically after the board arrives.

7. Debug hardware on the PCB is worth the effort. The five debug LEDs gave
immediate visual confirmation of UART RX, TX, MQTT activity, and WiFi status
during bring-up. Without them, figuring out whether a problem was in the firmware,
the wiring, or the MQTT connection would have required an oscilloscope every time.

8. Schematic net label naming should match firmware variable names. The USB
differential pair was labeled USB_N and USB_P in the schematic but referenced as
GPIO19 and GPIO20 everywhere else. That inconsistency caused confusion during
review. Keeping names consistent across the schematic, firmware, and datasheet
reduces errors.

9. Testing the failsafe explicitly is not optional. It would have been easy to
assume the WiFi failsafe worked without testing it. Actually verifying that the
emergency stop packet was broadcast over UART when the broker dropped gave real
confidence that the feature worked.

10. Documentation written during the design process is far better than
documentation written after. Pages written while design decisions were fresh were
more detailed and accurate than sections written later from memory. Keeping the
datasheet updated as decisions were made made the final report much easier to
complete.

---

## Recommendations for Future Students

1. Read the full assignment rubric before starting any design work. The final
report adds new required sections that are not in the early checkpoints. Knowing
what is coming from the beginning means you can structure your work to satisfy
those requirements as you go rather than adding missing sections at the end.

2. Get your development environment working on a commercial dev board before your
custom PCB arrives. Flash MicroPython onto an off-the-shelf ESP32-S3 dev board
and verify that WiFi, UART, and other peripherals work in software first. That
way you are debugging firmware and hardware separately, not at the same time.

3. Write down the UART protocol with your teammates before anyone starts coding.
Verbal agreements about packet formats lead to integration failures that are hard
to debug under time pressure. A shared document that everyone has reviewed and
agreed on is worth the thirty minutes it takes to write.

4. Order your PCB and components earlier than you think you need to. Shipping
delays and fabrication lead times are real. If your board arrives two weeks before
the showcase instead of four, you lose half your bring-up time. Build buffer into
your schedule deliberately.

5. Treat stretch goals as real goals with real schedules. The camera had a full
software stack built but was never demonstrated because the hardware bring-up
steps for the camera were not scheduled explicitly. If a feature matters enough
to implement, it matters enough to plan a verification timeline for it.

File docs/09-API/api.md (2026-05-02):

---
title: API - Firmware Behavior & UART Message Specification
tags:
- ESP32-S3
- UART
- MQTT
- Recon Amphibot
- EGR314
---

# API - Firmware Behavior & UART Message Specification

**Subsystem:** ESP32-S3 Wireless Communication Gateway  
**Board ID:** `'M'` (ASCII 0x4D)  
**Team:** 302 - R6 Recon Amphibot  

---

## Packet Frame (All Messages)

All messages follow the standardized 64-byte UART packet:
[ 0x41 | 0x5A | Source ID | Dest ID | Message (58 Bytes) | 0x59 | 0x42 ]

**All multi-byte values are transmitted in big-endian format.**

### Board IDs

| Board | Source / Dest ID | ASCII |
|---|---|---|
| ESP32 Wireless Gateway (Mihir) | `'M'` | 0x4D |
| Sensor + HMI PIC (Laksh) | `'L'` | 0x4C |
| Actuator PIC (Raunak) | `'R'` | 0x52 |
| Broadcast (all boards) | `'*'` | 0x2A |

---

## Message Responsibility Summary

### Messages Sent (by ESP32)
- `0x0001` — Motor Speed Command
- `0x0002` — Sensor Data Request
- `0x0005` — Emergency Stop
- `0x0008` — System Status
- `0x00FF` — Acknowledgement (ACK)

### Messages Received (by ESP32)
- `0x0003` — Sensor Data Response
- `0x0004` — Motor Telemetry
- `0x0006` — Error Code
- `0x0007` — Error Message
- `0x0043` — Button Event

### Broadcast Messages Handled
- `0x0005` Emergency Stop → immediate safe-stop + camera stream stop
- `0x0008` System Status → logged + forwarded to MQTT

---

## Firmware Overview

The ESP32 firmware performs:

1. Periodic sensor polling via UART every 15 seconds
2. Periodic system status broadcast every 15 seconds
3. UART message reception, routing, and forwarding
4. MQTT publish (telemetry, status, errors, heartbeat)
5. MQTT subscribe → UART command translation
6. Camera command handling (capture, stream on/off)
7. System failsafe (WiFi loss → emergency stop broadcast over UART)

---

## Firmware Constants

```python
MY_ID        = ord('M')   # 0x4D
SENSOR_ID    = ord('L')   # 0x4C
ACTUATOR_ID  = ord('R')   # 0x52
BROADCAST_ID = ord('*')   # 0x2A

HEADER     = bytes([0x41, 0x5A])   # 'A' 'Z'
FOOTER     = bytes([0x59, 0x42])   # 'Y' 'B'
PACKET_LEN = 64
SEND_INTERVAL_MS = 500             # minimum ms between UART transmissions

def build_packet(dest_id: int, msg_type: int, data: bytes) -> bytes:
    """Build a valid 64-byte UART packet."""
    assert len(data) <= 56, "Payload too long"
    # Sanitize payload to prevent accidental header/footer sequences
    clean = bytearray(data)
    for i in range(len(clean) - 1):
        if clean[i:i+2] == b'\x41\x5A' or clean[i:i+2] == b'\x59\x42':
            clean[i] = 0x00
    payload = bytearray([msg_type >> 8, msg_type & 0xFF])
    payload += bytearray(clean)
    while len(payload) < 58:
        payload += b'\x00'
    return HEADER + bytes([MY_ID, dest_id]) + bytes(payload) + FOOTER

def uart_send(packet: bytes):
    """Rate-limited UART transmit — enforces 500ms minimum interval."""
    assert len(packet) == PACKET_LEN
    uart.write(packet)

def is_valid_packet(frame: bytes) -> bool:
    return (
        len(frame) == PACKET_LEN
        and frame[0:2] == HEADER
        and frame[62:64] == FOOTER
    )
```

---

## UART ↔ MQTT Mapping

| UART Frame | Meaning | MQTT Topic | Payload |
|---|---|---|---|
| `0x0001 → 'R'` | Set motor speed | — | — |
| `0x0002 → 'L'` | Request sensor data | — | — |
| `0x0005 → '*'` | Emergency stop broadcast | `TOPIC_STATUS` | `"ESTOP"` |
| `0x0008 → '*'` | Status update broadcast | `TOPIC_STATUS` | status string |
| `0x0003` received | Sensor data | `TOPIC_TELEMETRY` | JSON |
| `0x0004` received | Motor telemetry | `TOPIC_TELEMETRY` | JSON |
| `0x0006` received | Error code | `TOPIC_ERROR` | JSON |
| `0x0007` received | Error message | `TOPIC_ERROR` | string |
| `0x0043` received | Button press | `TOPIC_STATUS` | `camera_capture btn=N` |

---

## MQTT Subscribe Commands

Commands received on `TOPIC_SUB` are translated into UART packets or camera actions:

| MQTT Command | Example | Action |
|---|---|---|
| `forward <rpm>` | `forward 500` | Sends `0x0001` to actuator, direction=1, rpm=500 |
| `reverse <rpm>` | `reverse 300` | Sends `0x0001` to actuator, direction=2, rpm=300 |
| `stop` / `estop` | `stop` | Broadcasts `0x0005` ESTOP, stops camera stream |
| `setpoint <rpm>` | `setpoint 400` | Sends `0x0001`, positive=forward, negative=reverse |
| `sensor <id>` | `sensor 1` | Sends `0x0002` sensor request to Sensor board |
| `status` | `status` | Broadcasts `0x0008` system status |
| `capture` | `capture` | Triggers single OV5640 JPEG capture → MQTT |
| `stream on` | `stream on` | Starts continuous JPEG stream → MQTT |
| `stream off` | `stream off` | Stops continuous JPEG stream |

---

## Camera MQTT Topics

The camera subsystem uses three dedicated MQTT topics, separate from the main
telemetry topics. These are defined in `config.py` via `config_additions.py`:

| Topic | Direction | Description |
|---|---|---|
| `TOPIC_CAM_CMD` | Subscribe (inbound) | Receives camera commands: `capture`, `stream on`, `stream off` |
| `TOPIC_CAM_FRAME` | Publish (outbound) | Chunked base64 JPEG frames, QoS 0 |
| `TOPIC_CAM_STATUS` | Publish (outbound) | Camera health and frame metadata, QoS 1 |

### Camera Frame Format

Each MQTT message on `TOPIC_CAM_FRAME` is a JSON object:

```json
{
  "seq":   1,
  "chunk": 0,
  "total": 3,
  "data":  "<base64-encoded JPEG bytes>"
}
```

The receiver reassembles chunks in order using `seq` and `chunk` indices.
Chunk size is 4096 bytes of raw JPEG per message (~5460 base64 characters).

### Button Event Camera Mapping

Button events received over UART (`0x0043`) are mapped to camera commands:

| Button Number | Camera Action |
|---|---|
| 1 | Single capture |
| 2 | Stream on |
| 3 | Stream off |
| Other | Publishes `camera_capture btn=N` to `TOPIC_STATUS` |

---

## Message Specifications

### `0x0001` — Motor Speed Command (SEND)

| Byte | Name | Type | Min | Max | Example |
|---|---|---|-----|-----|---|
| 4–5 | message_type | `uint16_t` | `0x0001` | `0x0001` | `0x0001` |
| 6 | direction | `uint8_t` | 0 | 2 | 1 |
| 7–8 | rpm | `uint16_t` | 0 | 2300 | 500 |

_Direction: 0=STOP, 1=FORWARD, 2=REVERSE. RPM range: 0–2300._

### `0x0002` — Sensor Request (SEND)

| Byte | Name | Type | Min | Max | Example |
|---|---|---|-----|-----|---|
| 4–5 | message_type | `uint16_t` | `0x0002` | `0x0002` | `0x0002` |
| 6 | sensor_id | `uint8_t` | 1 | 3 | 1 |

### `0x0003` — Sensor Data (RECEIVE)

| Byte | Name | Type | Min | Max | Example |
|---|---|---|-----|-----|---|
| 4–5 | message_type | `uint16_t` | `0x0003` | `0x0003` | `0x0003` |
| 6–7 | imu_tilt | `int16_t` | -18000 | 18000 | 450 |
| 8–9 | temperature | `int16_t` | -4000 | 12500 | 2350 |
| 10–11 | hazard_score | `uint16_t` | 0 | 10000 | 2500 |
| 12–13 | humidity | `uint16_t` | 0 | 10000 | 5500 |

_All values are fixed-point ×100._

### `0x0004` — Motor Telemetry (RECEIVE)

| Byte | Name | Type | Min | Max | Example |
|---|---|---|-----|-----|---|
| 4–5 | message_type | `uint16_t` | `0x0004` | `0x0004` | `0x0004` |
| 6 | direction | `uint8_t` | 0 | 2 | 1 |
| 7–8 | current_rpm | `uint16_t` | 0 | 2300 | 180 |

_Direction: 0=STOPPED, 1=FORWARD, 2=REVERSE._

### `0x0005` — Emergency Stop (SEND + RECEIVE + BROADCAST)

| Byte | Name | Type | Min | Max | Example |
|---|---|---|-----|-----|---|
| 4–5 | message_type | `uint16_t` | `0x0005` | `0x0005` | `0x0005` |
| 6 | stop_source | `uint8_t` | — | — | `'M'` |

_stop_source is the ASCII board ID of the board initiating the stop._

### `0x0006` — Error Code (RECEIVE)

| Byte | Name | Type | Min | Max | Example |
|---|---|---|-----|-----|---|
| 4–5 | message_type | `uint16_t` | `0x0006` | `0x0006` | `0x0006` |
| 6 | subsystem_id | `uint8_t` | — | — | `'L'` |
| 7 | error_code | `uint8_t` | 0 | 255 | 10 |

### `0x0007` — Error Message (RECEIVE)

| Byte | Name | Type | Min | Max | Example |
|---|---|---|-----|-----|---|
| 4–5 | message_type | `uint16_t` | `0x0007` | `0x0007` | `0x0007` |
| 6–60 | error_msg | `char[55]` | — | — | `"Motor fault"` |
| 61 | null | `uint8_t` | 0 | 0 | `0x00` |

### `0x0008` — System Status (SEND + BROADCAST)

| Byte | Name | Type | Min | Max | Example |
|---|---|---|-----|-----|---|
| 4–5 | message_type | `uint16_t` | `0x0008` | `0x0008` | `0x0008` |
| 6 | status_code | `uint8_t` | 0 | 4 | 1 |

_Status codes: 0=IDLE, 1=RUNNING, 2=WARNING, 3=ERROR, 4=ESTOP._

### `0x0043` — Button Event (RECEIVE)

| Byte | Name | Type | Min | Max | Example |
|---|---|---|-----|-----|---|
| 4–5 | message_type | `uint16_t` | `0x0043` | `0x0043` | `0x0043` |
| 6 | button_num | `uint8_t` | 1 | 8 | 1 |

### `0x00FF` — Acknowledgement (SEND)

| Byte | Name | Type | Min | Max | Example |
|---|---|---|-----|-----|---|
| 4–5 | message_type | `uint16_t` | `0x00FF` | `0x00FF` | `0x00FF` |
| 6–7 | acked_msg_type | `uint16_t` | `0x0001` | `0xFFFF` | `0x0003` |

---

## Receiver Implementation

```python
if src == MY_ID:
    continue   # drop looped-back own packets

if dest != MY_ID and dest != BROADCAST_ID:
    uart.write(frame)   # forward — not addressed to us
    return
```

---

## Sender Implementation

- Always send valid 64-byte packets.
- Respect `AZ` prefix and `YB` suffix.
- Sanitize payload to prevent accidental header/footer byte sequences.
- Rate-limit transmission — minimum 500ms between UART sends.
- Prioritize forwarding packets not addressed to this board.

---

## Acknowledgement Behavior

```python
def send_ack(dest_id: int, msg_type: int):
    data = bytes([msg_type >> 8, msg_type & 0xFF])
    ack = build_packet(dest_id, MSG_ACK, data)
    uart_send(ack)
```

ACKs are sent in response to: `0x0003`, `0x0004`, `0x0005`, `0x0006`,
`0x0007`, and `0x0043`.

---

## WiFi Failsafe Behavior

When the WiFi connection is lost, the firmware automatically:

1. Sets the WiFi LED (GPIO35) to OFF
2. Stops any active camera stream
3. Broadcasts an emergency stop packet (`0x0005`) over UART to all boards
4. Flashes all four LEDs three times to indicate the fault condition

```python
async def wifi_han(state):
    led_wifi.value(1 if state else 0)
    if not state:
        cam.stream_stop()
        uart.write(build_packet(BROADCAST_ID, MSG_EMERGENCY_STOP, bytes([MY_ID])))
```

---

## Notes

- Payload must not contain header (`0x41 0x5A`) or footer (`0x59 0x42`) byte sequences.
- All packets must be exactly 64 bytes.
- System enters safe-stop on WiFi loss automatically.
- UART forwarding takes priority over local processing.
- Heartbeat published to `TOPIC_HB` every 5 seconds to confirm broker connectivity.

---

## Example Frame

ESP32 (`Source ID = 'M'`) requests sensor data from the Sensor board
(`Dest ID = 'L'`):

- Byte 0: `0x41` (header 'A')
- Byte 1: `0x5A` (header 'Z')
- Byte 2: `0x4D` (Source ID = 'M', ESP32)
- Byte 3: `0x4C` (Dest ID = 'L', Sensor board)
- Byte 4: `0x00` (Message Type high byte)
- Byte 5: `0x02` (Message Type low byte → `0x0002` Request Sensor Data)
- Byte 6: `0x01` (Sensor ID)
- Byte 7–61: zero-filled/reserved
- Byte 62: `0x59` (footer 'Y')
- Byte 63: `0x42` (footer 'B')

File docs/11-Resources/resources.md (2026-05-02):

---
title: Resources
tags:
- Mihir's Individual Datasheet - Resources
---

# Resources

This page contains all final code files and downloadable project assets for the
ESP32 Wireless Communication subsystem.

---

## Final Code

The complete firmware for this subsystem consists of four files. All four are
included in the ZIP download below.

**mihir_esp32_main.py** — Main firmware file. Handles WiFi connection, MQTT
publish and subscribe, UART packet reception and forwarding, LED indicators,
periodic sensor polling, and the WiFi-loss emergency stop failsafe.

**camera_module.py** — Camera subsystem module. Handles OV5640 initialization,
single-frame JPEG capture, chunked base64 MQTT frame publishing, and continuous
streaming mode with configurable frame rate.

**config_additions.py** — Defines the three camera-specific MQTT topics that
are added to the existing config.py file: TOPIC_CAM_CMD, TOPIC_CAM_FRAME, and
TOPIC_CAM_STATUS.

**viewer.py** — Laptop-side viewer script. Subscribes to TOPIC_CAM_FRAME over
MQTT, reassembles chunked JPEG frames, and displays them in a live OpenCV window.
Run this on your laptop, not on the ESP32.

### Download

[Download Final ESP32 Code ZIP](Mihir_ESP32_Code_Final.zip)

---

## Schematic and PCB Files

These are also available on the Schematic and PCB pages but are collected here
for convenience.

- [Download KiCad Project ZIP](Patel_EGR314_projectzip_4_11.zip)
- [Download PCB Gerber Files ZIP](Gerber_drill_4_10_26.zip)
- [Download High-Resolution Schematic PDF](Patel_EGR314_Schematic_MP_4_11.pdf)

---

## 3D Printed Parts

The team designed and printed a half-cut body model of the R6 Recon Amphibot
for the Innovation Showcase. This was not a functional enclosure but rather a
display model to help visitors understand how the internal electronics would be
arranged inside the chassis, where each board would sit, and how the overall
robot would look when assembled. It gave people at the showcase a physical
reference for the project without needing to see the actual robot fully built.

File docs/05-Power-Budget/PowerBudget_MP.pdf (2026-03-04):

# Power Budget - Mihir Patel

Team Number: | | Team 302
Project Name: | | R6 Recon Amphibot
Team Member Names: | Lakshanand Sugumar, Raunak Singh Version: | 1B (updated components)
A. List ALL major components (active devices, integrated circuits, etc.) except for power sources, voltage regulators, resistors, capacitors, or passive elements
All Major Components Component Name Part Number Supply # Absolute | Total | Unit
ESP32-S3-Wi-Fi Module ESP32-S3-WROOM-1-N8R8 3.3V 1 500 Camera module (OV5640) OV5640 3.3V 1 250 Debug LEDs (SMD 0805) LG-R971-KN-1 3.3V 5 20 Tactile Switches CTS 222AMVBAR 3.3V 2 1 USB VBUS sense/logic --3.3V 3.3V 1 1 20 50 | 500 250 100 2 20 50 | mA mA mA mA mA Misc overhead / margin mA
B. Assign each major component above to ONE power rail below. Try to minimize the number of different power rails in the design.
+3.3V Power Rail Component Name Part Number Supply # Absolute | Total | Unit
ESP32-S3-Wi-Fi Module ESP32-S3-WROOM-1-N8R8 3.3V 1 500 Camera moduel (OV5640) OV5640 3.3V 1 250 Debug LEDs (SMD 0805) LG-R971-KN-1 3.3V 5 20 Tactile Switches CTS 222AMVBAR 3.3V 2 1 USB VBUS sense/logic --3.3V 3.3V 1 1 20 50 Subtotal Safety Margin (25%) Total Current Required on +3.3V Rail c1. Regulator or Source Choice Buck Switching Regulator 3.3V (2A) AP63203WU-7 +3.8V - 32V 1 2000 Total Remaining Current Available on 3.3V Rail | 500 250 100 2 20 Misc overhead / margin 50 922 25% 1152.5 2000 847.5 | mA mA mA mA mA mA mA mA
C. For each power rail above, select a specific voltage regulator using the same process as for major component selection. Confirm that the Total Remaining Current Available on
Power Rail | Component Name | Part Number | Supply | # | Absolute
Total
| | | | | | Unit
3.3V Power Rail | Buck Regulator (1.5A variant) | AP63203WU-7 | +3.8V - 32V | 1 | 2000 | 2000 mA
D. Select a specific external power source (wall supply or battery) for your system, and confirm that it can supply all of the regulators for all of the power rails simultaneously. If
External Power Source 1 Component Name Part Number Supply Output Absolute | Total | Unit
Power Source 1 Selection 9V AC-DC Wall Adapter WSU090-2500 100 ~ 240VAC 9V 2500 Power Rails Connected to External Power Source 1 +3.3V [Buck Regulator (2A variant)] AP63203WU-7 +3.8V - 32V 1 2000 Total Remaining Current Available on External Power Source 1 | 2500 2000 500 | mA mA mA
External Power Source 2 Component Name Part Number Supply Output Absolute | Total | Unit
Power Source 2 Selection | Battery (12V) - Raunak's shared power | B09ZTKTLGW | 12V | 12V | 7000 | 7000 | mA

Power Rails Connected to External Power Source 1

+3.3V [Buck Regulator (2A variant)] | AP63203WU-7 | +3.8V - 32V | 1 | 2000 | 2000 | mA
Total Remaining Current Available on External Power Source 1 | 5000 | mA
Notes
1. External Supply Voltage should be determined by the dropout voltage for the highest-voltage regulator (e.g., +14V for a +12V regulator). The WSU090-2500 outputs 9V DC, which is well above the AP63203WU-7's minimum input voltage of 3.8V, providing adequate dropout margin.
2. The AP63203WU-7 is rated for 2A continuous output current. Total required on the +3.3V rail including 25% safety margin is 1152.5 mA, well within the 2A rating, leaving 847.5
mA of regulator headroom.
3. The ESP32-S3 and OV2640 camera are unlikely to simultaneously draw peak current. In typical operation (MQTT active + camera streaming), total draw remains well under 900 mA.
4. If you have multiple units in your design (e.g., a base unit and remote unit) then you need a separate power budget for each unit.
5. Passive components (resistors, capacitors, inductors) are excluded from this power budget per EGR314 course guidelines.


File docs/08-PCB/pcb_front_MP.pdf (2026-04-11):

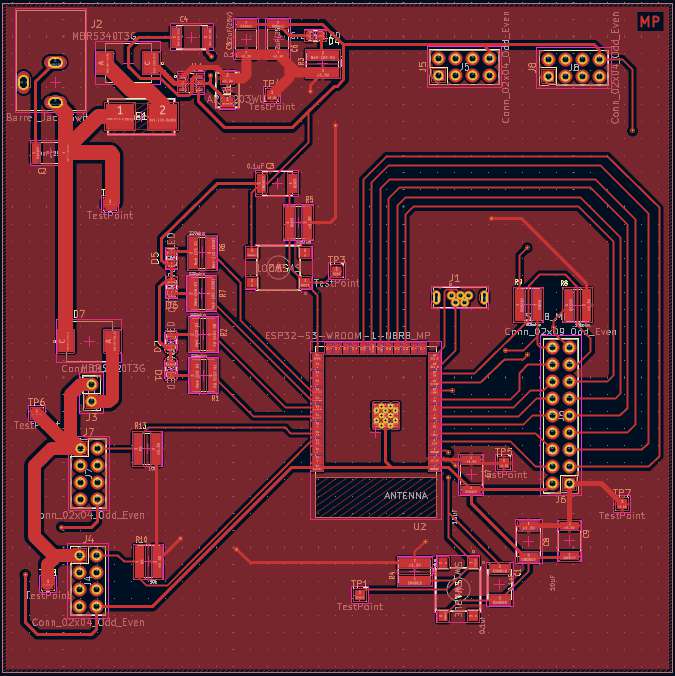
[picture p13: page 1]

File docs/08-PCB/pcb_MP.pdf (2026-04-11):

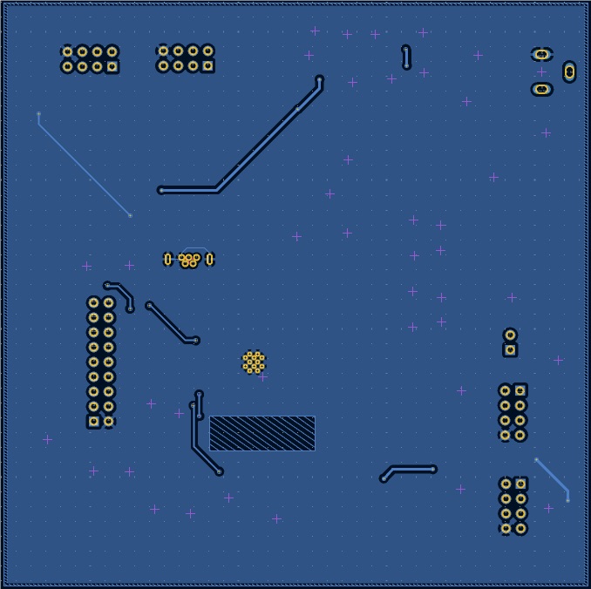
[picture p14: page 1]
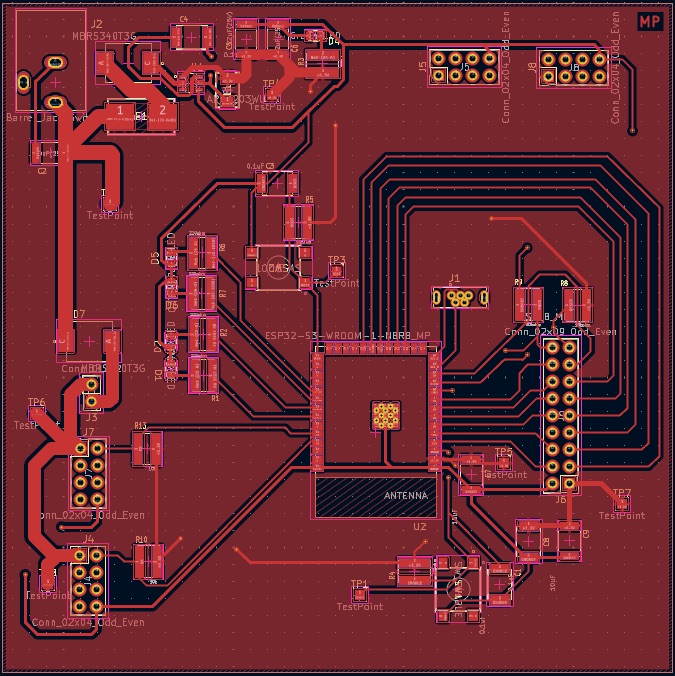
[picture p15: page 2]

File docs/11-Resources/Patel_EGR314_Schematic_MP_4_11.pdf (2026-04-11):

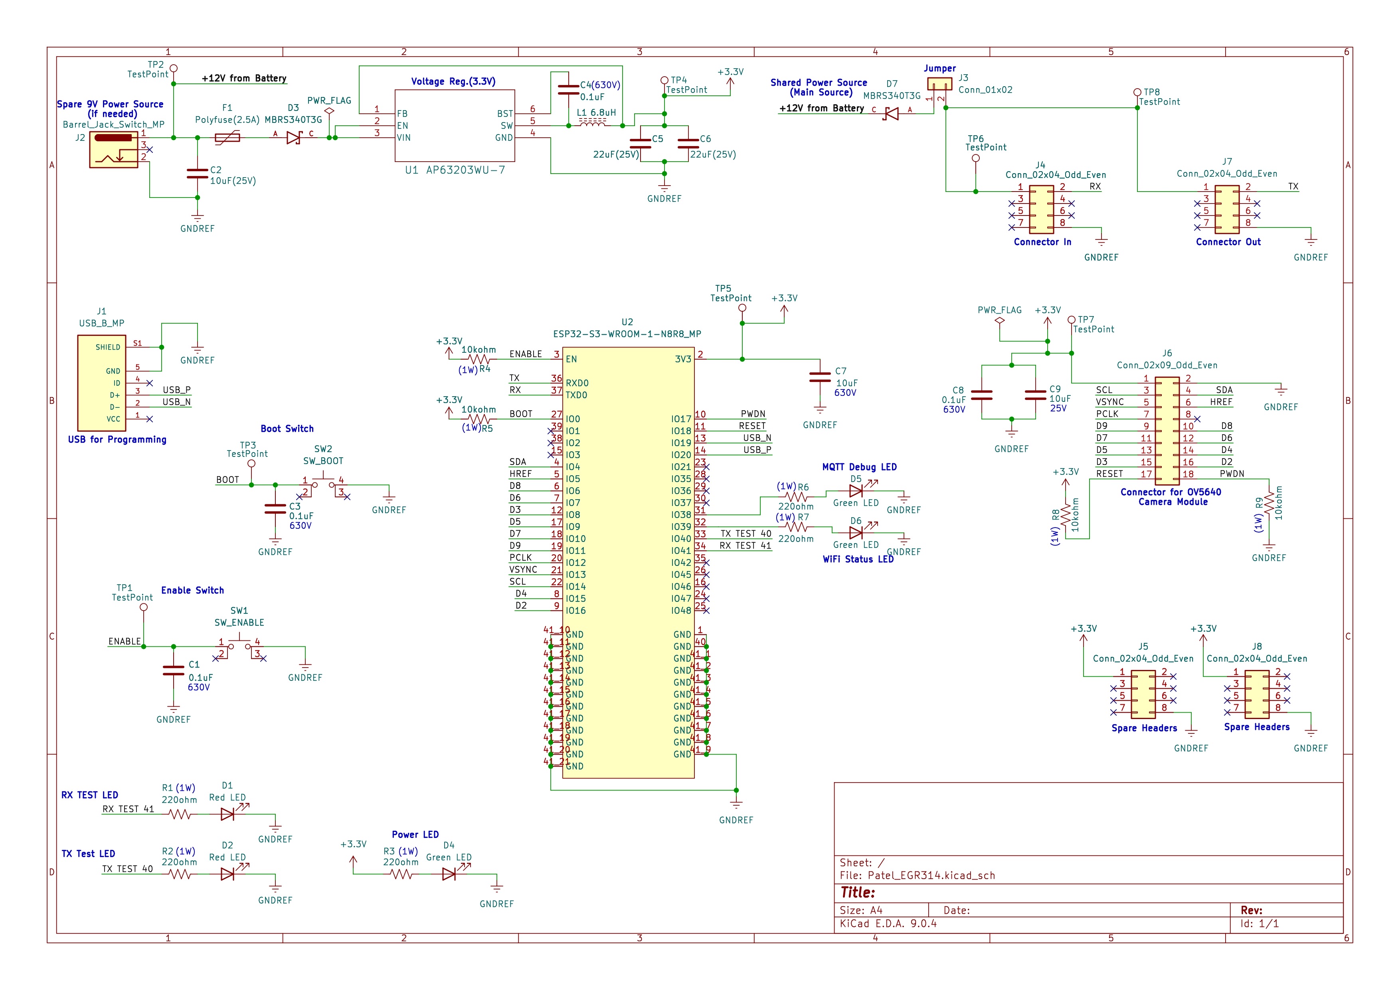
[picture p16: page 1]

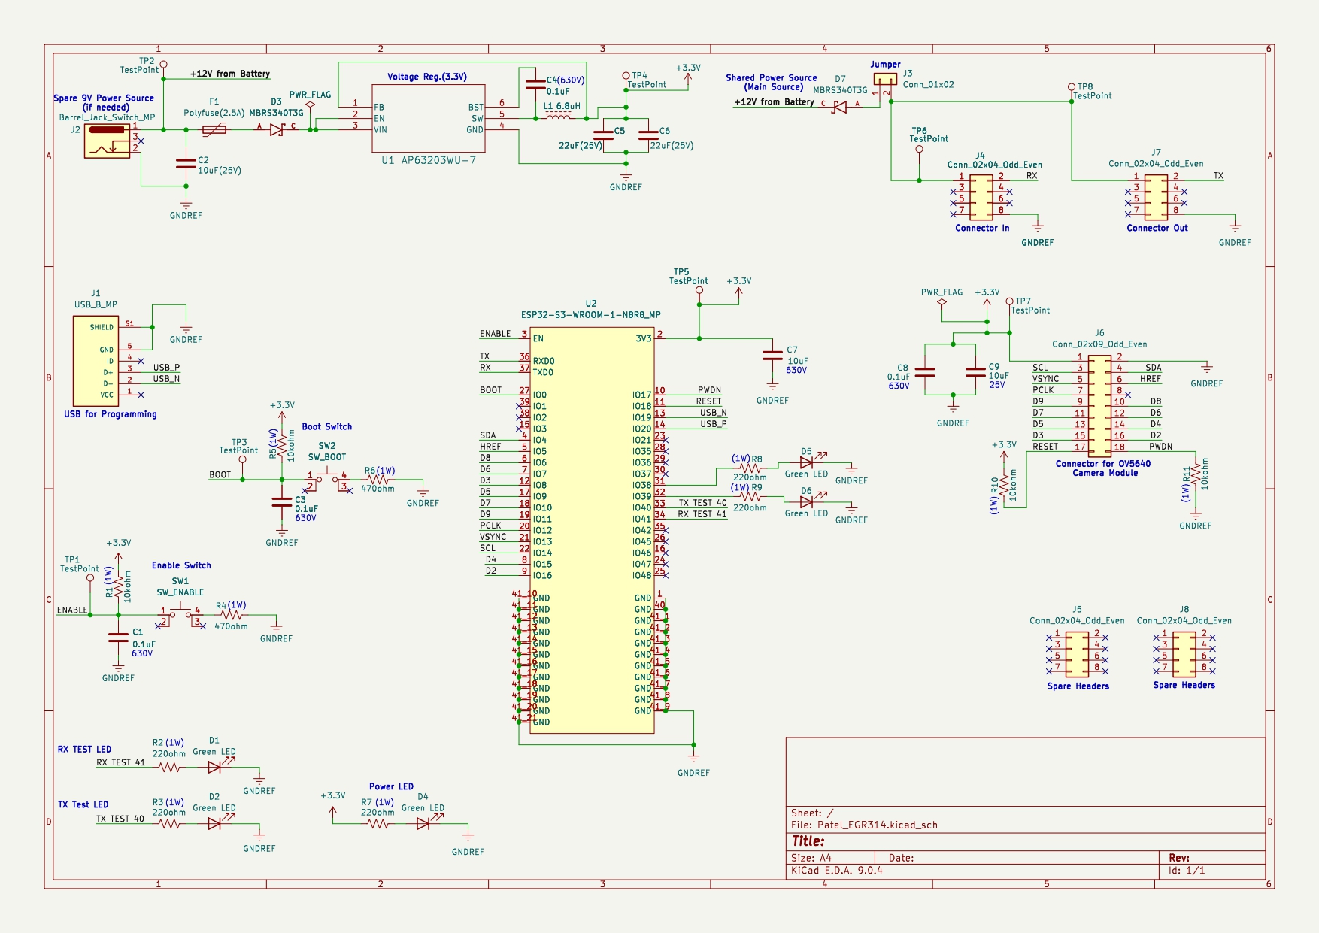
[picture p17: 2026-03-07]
docs/07-Schematic/Patel_EGR314_Schematic_MP_3_6.jpg

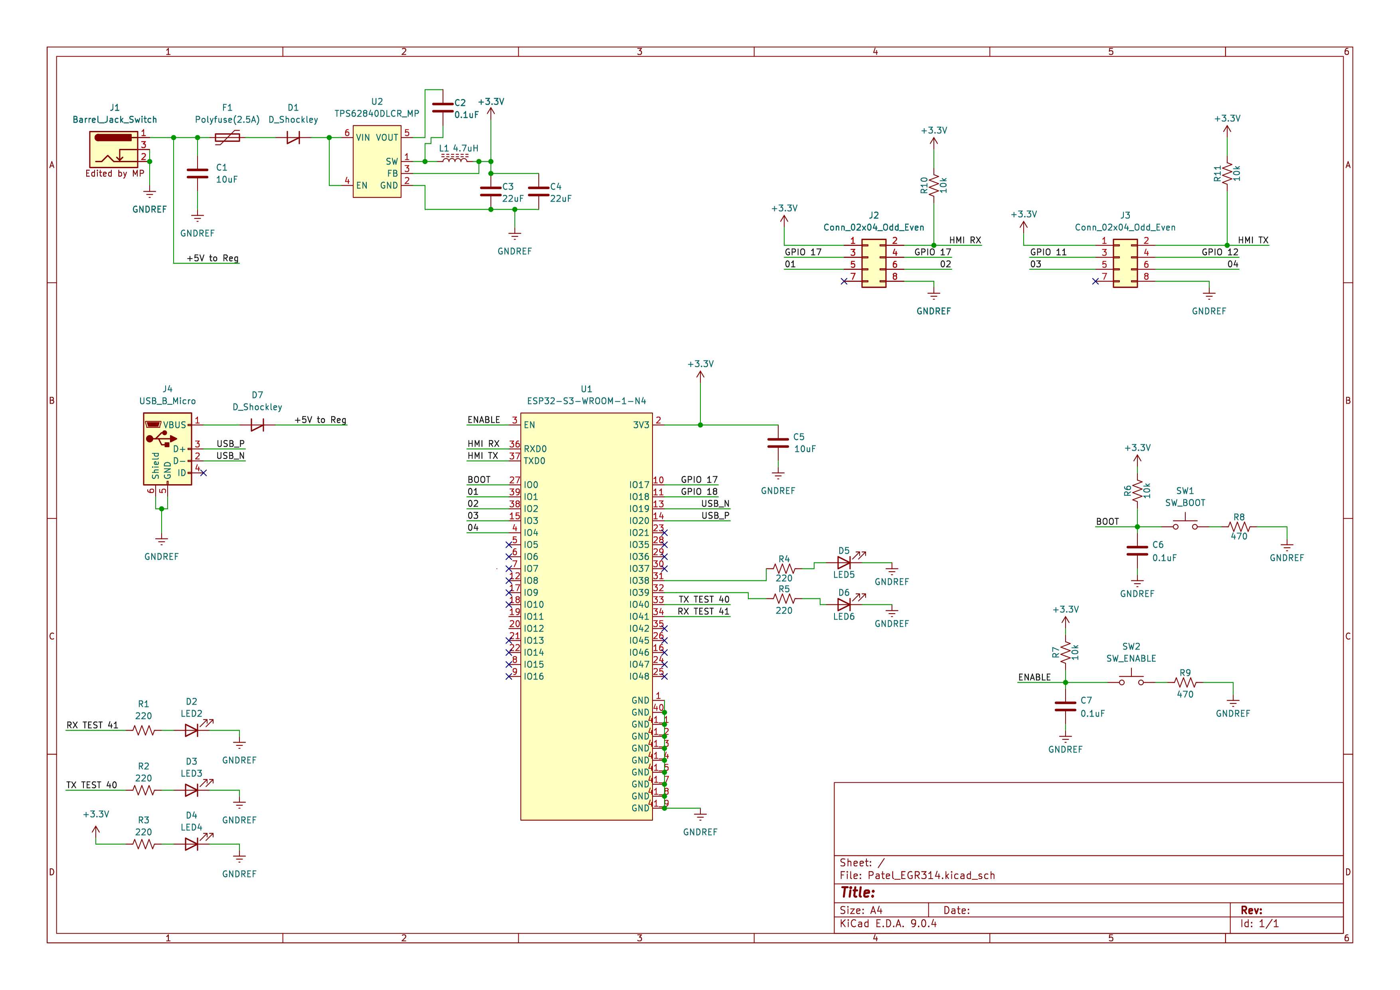
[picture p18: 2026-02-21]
docs/07-Schematic/EGR314_Schematic_Mihir.jpg

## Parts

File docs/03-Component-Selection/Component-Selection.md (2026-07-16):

---
title: Component Selection
tags:
  - ESP32 Wireless Communication Gateway
  - Component Selection
  - Hardware Design
---

# ESP32 Wireless Communication Gateway Component Selection  

## 1. Wireless Microcontroller / Wi-Fi Module **(Core Subsystem)**

### Option 1

| Solution | Pros | Cons |
|---|---|---|
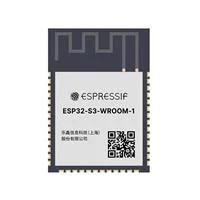
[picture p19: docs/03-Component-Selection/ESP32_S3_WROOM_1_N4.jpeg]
ESP32-S3-WROOM-1-N8R8
| **ESP32-S3-WROOM-1-N8R8 (SMD module)**<br><br>Surface-mount module with integrated RF, 8MB flash, 8MB PSRAM, dual-core CPU<br>Price: ≈ $6.13/each<br>[Product Page](https://www.digikey.com/en/products/detail/espressif-systems/ESP32-S3-WROOM-1-N8R8/15295891)<br>[Datasheet](https://documentation.espressif.com/esp32-s3-wroom-1_wroom-1u_datasheet_en.pdf) | - Integrated Wi-Fi and Bluetooth<br>- 8MB PSRAM enables OV5640 camera frame buffering<br>- Dual-core allows multitasking (MQTT + UART + camera)<br>- Same footprint as N4, drop-in replacement<br>- RF section already optimized inside module | - Slightly larger footprint than bare chip<br>- Requires antenna keepout area on PCB<br>- ~$1.07 more than N4 variant |

### Option 2

| Solution | Pros | Cons |
|---|---|---|
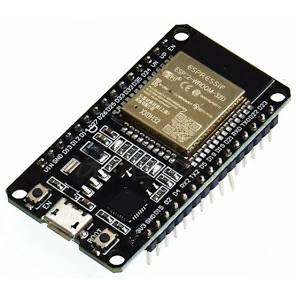
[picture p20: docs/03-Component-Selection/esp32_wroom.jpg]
ESP32-S3-WROOM
| **ESP32-WROOM (classic)**<br><br>Price: ≈ $6.56/each<br>[Datasheet](https://documentation.espressif.com/esp32-wroom-32_datasheet_en.pdf) | - Widely used and well-documented<br>- Reliable Wi-Fi performance<br>- Strong software ecosystem | - Older architecture compared to S3<br>- Fewer advanced features (USB support, improved peripherals)<br>- Higher cost than S3 module in this case |

### Option 3

| Solution | Pros | Cons |
|---|---|---|
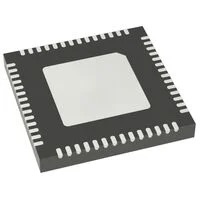
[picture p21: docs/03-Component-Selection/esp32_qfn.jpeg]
ESP32-S3
| **ESP32-S3 (bare QFN chip)**<br><br>Price: ≈ $2.13/each<br>[Datasheet](https://documentation.espressif.com/esp32-s3_datasheet_en.pdf)<br>Standalone MCU without integrated RF module packaging | - Lowest cost per unit<br>- Smallest PCB footprint<br>- Maximum control over layout and antenna design | - Requires custom RF layout and impedance matching<br>- Higher assembly difficulty (QFN package)<br>- Increased design risk for first PCB revision |

**Choice:** Option 1 — ESP32-S3-WROOM-1-N8R8
**Rationale:** The ESP32-S3-WROOM-1-N8R8 module is selected because it provides the most reliable and capable solution for implementing Wi-Fi, MQTT communication, and OV5640 camera streaming in this subsystem. The 8MB PSRAM is a hard requirement, without it, the `esp_camera` driver cannot allocate frame buffers at usable resolutions, and the camera integration would fail entirely. The $1.07 cost increase over the N4 variant is fully justified by this capability.

The S3 architecture also provides improved performance and peripheral support compared to the classic ESP32-WROOM-32, while still remaining affordable. Its dual-core design allows separation of networking tasks (MQTT publishing, reconnection handling) from UART daisy-chain communication and camera data processing simultaneously. The N8R8 uses the identical PCB footprint as the N4, meaning no layout changes were required when upgrading. Although the module has a slightly larger footprint than the bare QFN chip, the reduction in RF tuning risk, integrated PSRAM, and faster bring-up time make it the optimal choice for this project.

---

## 2. 3.3 V Switching Regulator **(Voltage Regulation)**

### Option 1

| Solution | Pros | Cons |
|---|---|---|
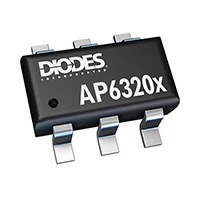
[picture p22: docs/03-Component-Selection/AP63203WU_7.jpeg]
AP63203WU-7
| **AP63203WU-7**<br><br>2A synchronous buck regulator, SOT-23-6 package, fixed 3.3V output<br>Price: $0.71/each<br>[Product Page](https://www.digikey.com/en/products/detail/diodes-incorporated/AP63203WU-7/9858426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)<br>[Datasheet](https://www.diodes.com/assets/Datasheets/AP63200-AP63201-AP63203-AP63205.pdf) | - Very compact SOT-23 package<br>- Low cost and widely available<br>- Simple external component requirements<br>- Fully SMD compatible | - Moderate efficiency under higher load<br>- Can generate noticeable heat during Wi-Fi transmit bursts<br>- Limited current margin for future expansion |

### Option 2

| Solution | Pros | Cons |
|---|---|---|
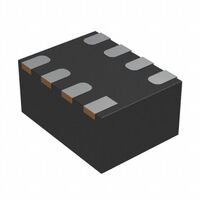
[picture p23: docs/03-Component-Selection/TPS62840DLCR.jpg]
TPS62840DLCR
| **TI TPS62840DLCR**<br><br>High-efficiency synchronous buck converter, optimized for low quiescent current and battery-powered systems<br>Price: $2.08/each<br>[Product Page](https://www.digikey.com/en/products/detail/texas-instruments/TPS62840DLCR/10445071)<br>[Datasheet](https://www.ti.com/lit/ds/symlink/tps62840.pdf?ts=1770872928987) | - Up to 95% efficiency across wide load range<br>- Excellent transient response for radio current spikes<br>- Very low quiescent current (good for battery demos)<br>- Lower heat generation compared to basic buck regulators | - Higher cost than AP63203<br>- Requires careful PCB layout and proper inductor selection<br>- Slightly more complex BOM |

### Option 3

| Solution | Pros | Cons |
|---|---|---|
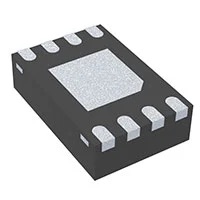
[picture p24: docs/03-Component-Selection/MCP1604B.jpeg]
MCP1640B
| **MCP1640B Boost + LDO Combination (PMIC-style approach)**<br><br>High-efficiency DC-DC converter combined with linear regulator for multi-rail designs<br>Price: $0.81/each<br>[Product Page](https://www.digikey.com/en/products/detail/microchip-technology/MCP1640B-I-MC/2258562)<br>[Datasheet](https://ww1.microchip.com/downloads/aemDocuments/documents/APID/ProductDocuments/DataSheets/MCP1640-Family-Data-Sheet-DS20002234E.pdf) | - Flexible voltage configuration<br>- Can support additional rails in future revisions<br>- Efficient switching topology | - More complex design than needed for single 3.3V rail<br>- Larger PCB footprint<br>- Extra components increase layout difficulty |

**Choice:** Option 1 — AP63203WU-7
**Rationale:** I chose the AP63203WU-7 because it keeps the power circuit simple while still meeting the current requirements of the ESP32-S3. The fixed 3.3V output means I don't need to calculate or place feedback resistors, the datasheet application circuit is just an inductor and two capacitors, which is exactly what's shown in my schematic. At 600 mA output, it comfortably handles the ESP32's typical operating current with enough headroom for Wi-Fi bursts.

I did consider the TPS62840 for its higher efficiency, but after looking at the numbers, the AP63203 is more than adequate for this design. The ESP32-S3 draws around 250–350 mA during active Wi-Fi transmission, which is well within the AP63203's rating. The efficiency difference doesn't justify paying three times the price, especially since this board will mostly be powered from a bench supply during demos rather than running on battery. The MCP1640B is a boost converter, which steps voltage up, so it simply can't be used to regulate down from 9V, that option was eliminated right away.

---

## 3. Power Input / Connector Strategy **(Power Input)**

### Option 1

| Solution | Pros | Cons |
|---|---|---|
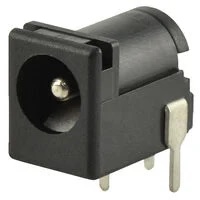
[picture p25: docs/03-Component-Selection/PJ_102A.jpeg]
PJ-102A
| **CUI Devices PJ-102A DC Barrel Jack (2.1mm)**<br><br>Through-hole DC barrel jack connector, 5.5mm OD / 2.1mm ID, widely used in lab power supplies<br>Price: $0.59/each<br>[Product Page](https://www.digikey.com/en/products/detail/same-sky-formerly-cui-devices/PJ-102A/275425)<br>[Datasheet](https://www.sameskydevices.com/product/resource/pj-102a.pdf) | - Mechanically strong and reliable<br>- Standard lab power connector<br>- Compatible with common 9V wall adapters<br>- Easy to solder and secure to PCB | - Larger footprint than USB-C<br>- Requires external wall adapter |

### Option 2

| Solution | Pros | Cons |
|---|---|---|
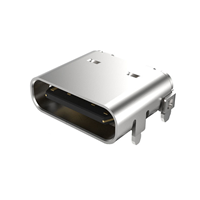
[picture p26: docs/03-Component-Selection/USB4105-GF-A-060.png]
USB-C
| **USB Type-C Receptacle (GCT USB4105-GF-A)**<br><br>Mid-mount USB-C connector supporting up to 3A current<br>Price: $0.78/each<br>[Product Page](https://www.digikey.com/en/products/detail/gct/USB4105-GF-A-060/14559036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)<br>[Datasheet](https://gct.co/files/specs/usb4105-spec.pdf) | - Reversible and modern connector<br>- Can support both power and data<br>- Compact profile | - Requires CC resistors or PD controller configuration<br>- More complex routing and ESD protection<br>- Less mechanically robust than barrel jack in repeated demo use |

### Option 3

| Solution | Pros | Cons |
|---|---|---|
| **JST-PH 2-Pin Connector (B2B-PH-K-S)**<br>JST-PH (B2B-PH-K-S)<br>2.0mm pitch PCB header for battery connection, compact and lightweight<br>Price: $0.10/each<br>[Product Page](https://www.digikey.com/en/products/detail/jst-sales-america-inc/B2B-PH-K-S/926611)<br>[Datasheet](https://www.jst-mfg.com/product/pdf/eng/ePH.pdf) | - Very compact footprint<br>- Ideal for Li-ion battery integration<br>- Low cost | - Not ideal for wall power supplies<br>- Lower mechanical retention compared to barrel jack<br>- Requires separate charging circuitry |

**Choice:** Option 1 —  CUI PJ-102A DC Barrel Jack + Board Jumpers  
**Rationale:** The DC barrel jack is selected because it aligns directly with the EGR314 project requirements, which specify the use of a barrel-jack adapter and jumper-controlled bus power integration. This ensures compatibility with standard 9V lab power supplies and simplifies system-level verification.

While USB-C offers a more modern interface, it introduces additional complexity such as configuration channel resistors, potential Power Delivery negotiation, and stricter layout requirements. For a student-built PCB focused on reliable wireless communication, that added complexity is unnecessary.

The JST battery connector is compact and useful for portable designs, but it does not meet the course expectation for wall-powered lab testing and demonstration.

By choosing the barrel jack, I ensure mechanical robustness, compliance with course standards, and straightforward hardware verification during external design review.

---

## 4. Antenna Solution **(RF Subsystem)**

### Option 1

| Solution | Pros | Cons |
|---|---|---|
| **Johanson 2450AT18A100E Chip Antenna (2.4 GHz SMD)**<br>Johanson Chip Antenna<br>Compact 2.4 GHz surface-mount ceramic chip antenna requiring matching network<br>Price: $0.51/each<br>[Product Page](https://www.digikey.com/en/products/detail/johanson-technology-inc/2450AT18A0100001E/1560676)<br>[Datasheet](https://www.johansontechnology.com/docs/1129/2450AT18A100E-AEC_tCZ7Fpd.pdf) | - Designed specifically for 2.4 GHz Wi-Fi/Bluetooth<br>- Repeatable RF performance across builds<br>- Small footprint and SMD compatible<br>- Industry-standard component | - Requires proper impedance matching network<br>- Strict PCB layout and ground keepout requirements<br>- Slightly increases BOM count |

### Option 2

| Solution | Pros | Cons |
|---|---|---|
| **ESP32-S3-WROOM-1-N8R8 (SMD Module with Integrated PCB Antenna)**<br>ESP32 Integrated Antenna<br>Module variant with built-in PCB trace antenna, 8MB Flash, 8MB PSRAM<br>Price: ≈ $6.13/each<br>[Product Page](https://www.digikey.com/en/products/detail/espressif-systems/ESP32-S3-WROOM-1-N8R8/15295891)<br>[Datasheet](https://documentation.espressif.com/esp32-s3-wroom-1_wroom-1u_datasheet_en.pdf) | - Simplest implementation — no extra antenna component<br>- RF section pre-designed and certified by Espressif<br>- 8MB PSRAM enables camera frame buffering for OV5640<br>- Same footprint as N4 variant — drop-in replacement<br>- Reduces external BOM parts | - Performance depends on host PCB placement<br>- Must strictly follow antenna clearance recommendations<br>- Slightly higher cost than N4 variant (~$0.44 more)<br>- Slightly less flexible for tuning or upgrades |

### Option 3

| Solution | Pros | Cons |
|---|---|---|
| **u.FL / IPEX Connector + External 2.4 GHz Antenna - 66089-2406**<br>uFL Connector<br>Miniature RF connector allowing detachable external antenna<br>Price: $6.52/each (connector only)<br>[Product Page](https://www.digikey.com/en/products/detail/ttm-technologies-inc/66089-2406/3069146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)<br>[Datasheet](https://cdn.ttm.com/repository/products/wireless-air-products/antennas/66089-2406/66089-xxxx_ProductBrief.pdf) | - Allows use of higher-gain external antennas<br>- Easy antenna swapping during testing<br>- Best option for maximum range | - Connector is mechanically fragile<br>- Adds cost and PCB area<br>- Not ideal for repeated demo handling |

**Choice: Option 2 — ESP32-S3-WROOM-1-N8R8 with Integrated PCB Antenna**

**Rationale:** I chose the ESP32-S3-WROOM-1-N8R8 specifically because it's the only variant in the WROOM-1 family that includes both 8MB of flash and 8MB of PSRAM in the same module footprint. The PSRAM is what makes the OV5640 camera integration possible without it, there's nowhere to store camera frame buffers, and the esp_camera driver simply won't initialize at any useful resolution. Upgrading from the N4 to the N8R8 costs about $0.44 more per board, which is a completely worthwhile trade for gaining full camera functionality.

Beyond the PSRAM advantage, the integrated PCB antenna version was chosen over the discrete chip antenna and u.FL connector options for the same reasons. Since the RF section is already designed, tuned, and pre-certified by Espressif, I don't need to worry about impedance matching, antenna keepout zones, or layout-induced RF performance issues on a first revision PCB. A discrete chip antenna would require a properly tuned matching network and strict ground plane management, that's extra design risk I don't need on a student board with a tight timeline.

The u.FL connector option would allow swapping in a higher-gain external antenna, which sounds useful, but the connector itself is mechanically fragile and gets damaged easily with repeated plugging during lab testing and demo sessions. For a board that's going to be handled a lot during the Innovation Showcase, that's a real concern.

The N8R8 with integrated antenna keeps the design compact, the BOM simple, and the RF bring-up risk low, while unlocking the full camera streaming capability the subsystem needs.

---

## 5. USB ↔ UART / Programming Interface **(Bring-up / OTA)**

### Option 1

| Solution | Pros | Cons |
|---|---|---|
| **Native USB (ESP32-S3 USB D+/D− Pins)**<br>ESP32 USB<br>Utilizing the ESP32-S3's built-in USB interface for programming and serial communication<br>Price: Included in MCU cost<br>[Product Page](https://www.digikey.com/en/products/detail/espressif-systems/ESP32-S3-WROOM-1-N4/16162639)<br>[Datasheet](https://documentation.espressif.com/esp32-s3-wroom-1_wroom-1u_datasheet_en.pdf) | - No additional USB-UART chip required<br>- Simplest hardware design<br>- Supports direct flashing and serial monitor<br>- Reduces BOM cost and PCB area | - Requires correct routing of USB differential pair<br>- Must follow USB layout guidelines carefully<br>- Not all module variants expose USB pins |

### Option 2

| Solution | Pros | Cons |
|---|---|---|
| **Silicon Labs CP2102N USB-to-UART Bridge**<br>CP2102N<br>High-speed USB-to-UART bridge, widely used in development boards<br>Price: $4.14/each<br>[Product Page](https://www.digikey.com/en/products/detail/silicon-labs/CP2102N-A02-GQFN20/9863475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)<br>[Datasheet](https://www.silabs.com/documents/public/data-sheets/cp2102n-datasheet.pdf) | - Reliable and widely supported drivers<br>- Very common in ESP32 development boards<br>- Simple UART integration<br>- Reduces risk if USB peripheral configuration fails | - Adds extra component and footprint<br>- Slightly increases BOM cost<br>- Additional routing required |

### Option 3

| Solution | Pros | Cons |
|---|---|---|
| **2×5 Programming Header (Tag-Connect / 0.1" Header)**<br>Programming Header<br>Standard programming/debug header for external USB-to-serial adapter<br>Price: $1.80/each<br>[Product Page](https://www.sparkfun.com/shrouded-header-pth-0-1in-2x5-pin.html)<br>[Datasheet](https://cdn.sparkfun.com/assets/2/e/c/e/1/Shrouded-10pin.pdf) | - Very low cost<br>- Minimal onboard components<br>- Useful for low-level debugging | - Requires external USB-to-serial adapter<br>- Less convenient during demos<br>- Extra cables increase setup complexity |

**Choice:** Option 1 — Micro USB SMD Connector (Native USB)  
**Rationale:** The Micro USB connector serves two purposes on my board, it acts as a secondary power input through VBUS (protected by a Schottky diode D7 so it doesn't fight with the barrel jack), and it's the primary way I'll be flashing firmware using the ESP32-S3's native USB pins. Because the S3 already has USB D+ and D− built in, I don't need a separate USB-to-UART chip at all. That saves me a chip, the routing that comes with it, and about $4 off the BOM.

I looked at using USB-C with a CP2102N bridge, which is how a lot of commercial ESP32 boards are designed, but it felt like overkill here. The CP2102N works great, but it adds another IC to place and route, and since the S3 natively supports USB, it's just extra complexity for no real benefit. The 2×5 header-only option was the other end of the spectrum which is cheaper, but requiring an external adapter every time I want to flash code is something I didn't want to deal with, especially during back-to-back verification sessions. Having the USB connector directly on the board is just much more convenient.

---

## 6. Input Protection & EMI Filtering **(Input Protection)**

### Option 1

| Solution | Pros | Cons |
|---|---|---|
| **SMBJ9.0A TVS Diode + LC Input Filter**<br>TVS Diode<br>Transient Voltage Suppression diode combined with series inductor and bulk capacitor for EMI filtering<br>TVS Price: $0.33/each<br>[TVS Product Page](https://www.digikey.com/en/products/detail/littelfuse-inc/SMBJ9-0A/688270)<br>[TVS Datasheet](https://www.littelfuse.com/assetdocs/tvs-diodes-smbj-series-datasheet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)<br>Inductor: $0.71/each<br>[Inductor Product Page](https://www.digikey.com/en/products/detail/bourns-inc/SRR0603-150ML/2563518) | - Protects against voltage spikes and transients<br>- Reduces conducted EMI from switching regulator<br>- Improves robustness when using ribbon cable bus<br>- Relatively low added cost | - Adds extra components to BOM<br>- Requires careful placement near input connector |

### Option 2

| Solution | Pros | Cons |
|---|---|---|
| **Schottky Diode + Polyfuse**<br>Schottky Diode<br>Schottky diode for reverse polarity/path isolation + resettable polyfuse for overcurrent<br>Diode Price: $0.25/each<br>[Product Page](https://www.sparkfun.com/schottky-diode-40v-1a-ss14-e3-61t.html)<br>[Datasheet](https://cdn.sparkfun.com/assets/e/d/0/b/0/SS14-E3_61T-datasheet-COM-29464.pdf) | - Simple and low cost<br>- Schottky provides reverse polarity and path-OR protection<br>- Polyfuse is resettable, no need to replace blown fuses during testing<br>- Widely understood and easy to debug | - Schottky has a small forward voltage drop (~0.3V)<br>- Polyfuse has some resistance and may trip under high transient load |

### Option 3

| Solution | Pros | Cons |
|---|---|---|
| **Pi Filter + Common-Mode Choke (WE-CNSW 744231091)**<br>Common Mode Choke<br>Common-mode choke combined with capacitors for strong EMI suppression<br>Price: $1.13/each<br>[Product Page](https://www.digikey.com/en/products/detail/w%C3%BCrth-elektronik/744231091/2650431)<br>[Datasheet](https://www.we-online.com/components/products/datasheet/744231091.pdf) | - Excellent EMI suppression<br>- Reduces noise coupling between boards<br>- Useful for compliance-focused designs | - Larger footprint<br>- Higher cost<br>- Overkill for small low-voltage system |

**Choice:** Option 2 — Schottky Diode (D_Shockley) + Polyfuse (F1)   
**Rationale:** I went with a Schottky diode and polyfuse combination because it covers the two most likely failure scenarios during development, accidental reverse polarity and overcurrent from a short circuit, without overcomplicating the design. The Schottky diode on the barrel jack input (D1) blocks reverse voltage if the supply is plugged in backwards, which is an easy mistake to make in a busy lab. It also does the power-path OR-ing between the barrel jack and USB VBUS so both supplies can be connected at the same time without one backfeeding the other. The board mount fuse F1 (015402.5DRT) handles overcurrent, if something shorts during bring-up, the fuse blows and the holder allows easy replacement without soldering, so I can swap in a fresh fuse and get back to testing quickly.

The TVS diode option is better for protecting against voltage spikes on long cable runs, which isn't really the concern here since we're running off a regulated bench supply. The common-mode choke would help with EMI, but for a 9V/3.3V low-frequency system it's completely unnecessary and adds cost and footprint. The Schottky + polyfuse approach is simple, proven, and practical for a student lab environment.

---

## 7. Power Path Jumpers (Bus Power Control)

### Option 1

| Solution | Pros | Cons |
|---|---|---|
| **2-Position 2.54mm Jumper (Wurth 732-13618-ND)**<br>Wurth 732-13618-ND<br>Standard 2-pin shorting jumper, 2.54mm pitch<br>Price: ~$0.35/each<br>[Product Page](https://www.digikey.com/en/products/detail/w%C3%BCrth-elektronik/609002115121/9920882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)<br>[Datasheet](https://www.we-online.com/components/products/datasheet/609002115121.pdf) | - Fulfills EGR314 required jumper specification directly<br>- Standard 0.1" pitch — easy to manually place/remove<br>- Extremely low cost<br>- No tools needed for reconfiguration | - Manual operation only (not software switchable)<br>- Small size can be lost during lab sessions |

### Option 2

| Solution | Pros | Cons |
|---|---|---|
| **SPDT Slide Switch**<br>Small SMD slide switch for bus power toggling<br>Price: ~$0.40–$0.80/each | - Stays in set position without falling off<br>- More user-friendly than removable jumpers | - Larger footprint than a 2-pin header<br>- Not the standard EGR314 jumper approach<br>- Harder to source in SMD form |

### Option 3

| Solution | Pros | Cons |
|---|---|---|
| **P-channel MOSFET Power Switch**<br>Soft-switching via GPIO control<br>Price: ~$0.50–$1.00/each | - Software controllable<br>- No manual intervention needed | - Significantly more complex — gate driver, pull resistors needed<br>- Overkill for a simple power isolation requirement<br>- Not aligned with course specification |

**Choice:** Option 1 — Wurth 732-13618-ND 2-Position Jumper  
**Rationale:** The course spec explicitly requires two jumpers per board, one to connect or disconnect bus power from the regulator, and one to connect or disconnect the barrel jack from the bus. The Wurth 732-13618-ND is a standard 2.54mm shorting jumper that fits a regular 2-pin header, so it satisfies that requirement directly with no fuss. Being able to physically remove a jumper to isolate my board from the team bus is really useful during debugging, because it means I can test my subsystem independently before connecting it to everyone else's hardware.

A slide switch would also work, but it takes up more PCB space and isn't the typical way jumpers are implemented in EGR314 designs. A MOSFET-based software switch could do the same thing and add remote controllability, but that would need a gate driver circuit, pull resistors, and firmware support, way more complexity than what this requirement calls for. A simple removable jumper does the job perfectly.

---

## 8. GPIO Headers & Expansion Pins (Connectivity)

### Option 1

| Solution | Pros | Cons |
|---|---|---|
| **Harwin M52-040023V2045 (2×10, 1.27mm pitch SMD)**<br>Harwin M52-040023V2045 (2×10, 1.27mm pitch SMD)<br>SMD vertical header, 20-pin, 1.27mm pitch<br>Price: ~$2.94/each<br>[Product Page](https://www.digikey.com/en/products/detail/harwin-inc/M52-040023V2045/6797702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)<br>[Datasheet](https://content.harwin.com/m/d0f746354cedd7a4/original/PD002-Product-Datasheet-ARCHER-M50-and-M52-ranges-BBi.pdf) | - Compact 1.27mm pitch saves PCB area<br>- SMD compatible — no drilling required<br>- Provides access to ESP32 GPIO, UART, and debug pins<br>- Sufficient pin count for all required signals | - Smaller pitch requires careful soldering<br>- Not compatible with standard 0.1" breadboard jumpers |

### Option 2

| Solution | Pros | Cons |
|---|---|---|
| **Standard 2.54mm Through-Hole Pin Header (1×10 or 2×5)**<br>Price: ~$0.20–$0.40/each | - Universal 0.1" pitch — works with standard jumper wires<br>- Easy to hand solder | - Larger PCB footprint<br>- Through-hole requires drilling in PCB<br>- Less professional appearance for a compact SMD design |

### Option 3

| Solution | Pros | Cons |
|---|---|---|
| **No Expansion Headers (Direct Trace Routing Only)**<br>Price: $0 | - Minimum PCB area used<br>- Cleanest board layout | - No external probe access to GPIO signals<br>- Makes debugging extremely difficult<br>- Fails to support team integration requirements |

**Choice:** Option 1 — Harwin M52-040023V2045  
**Rationale:** I chose the Harwin M52-040023V2045 because it gives me a way to break out the key GPIO signals I need, RX/TX, UART daisy chain lines, BOOT, ENABLE, and some spare pins, in a compact SMD footprint that keeps the board looking clean. The 1.27mm pitch is smaller than a standard 0.1" header, but it's still solderable by hand and the pin count is enough to expose everything I need without running out of space.

Standard through-hole 0.1" headers would definitely be easier to plug jumper wires into, but they require drilling the PCB and take up significantly more area. For a subsystem board that's already fairly busy with the ESP32 module, regulator, protection circuitry, and connectors, saving that space matters. Leaving out expansion headers entirely wasn't really an option either, without them, it would be very difficult to probe signals or connect to teammate boards during integration, which would slow down the whole team's verification process.

---

## 9. Daisy Chain Connectors (Upstream / Downstream)

### Option 1

| Solution | Pros | Cons |
|---|---|---|
| **2×4 IDC Female Header (8-pin, 2.54mm pitch)**<br>Standard 8-wire ribbon cable IDC connector for EGR314 daisy chain bus<br>Price: ~$0.50–$0.80/each<br>[Product Page](https://www.digikey.com/en/products/detail/marutsuelec/21602X40GSE/21669085)<br>[Datasheet](https://www.marutsu.co.jp/contents/shop/marutsu/datasheet/2160.pdf) | - Directly specified by EGR314 project requirements<br>- Keyed IDC connector prevents incorrect insertion<br>- Compatible with standard ribbon cable assemblies<br>- Provides all required pins: VCC, GND, UART TX/RX, and extra GPIO | - Through-hole mounting required<br>- Slightly larger footprint than custom connectors |

### Option 2

| Solution | Pros | Cons |
|---|---|---|
| **JST-XH 8-Pin Connector**<br>Price: ~$0.30/each | - Compact and lightweight<br>- Secure locking mechanism | - Not the EGR314 specified connector standard<br>- Not compatible with team ribbon cable assemblies<br>- Would require custom cables |

### Option 3

| Solution | Pros | Cons |
|---|---|---|
| **Screw Terminal Block (8-pin)**<br>Price: ~$1.00/each | - Very robust mechanical connection<br>- Easy wire attachment | - Very large PCB footprint<br>- Not IDC ribbon cable compatible<br>- Does not meet course connector standard |

**Choice:** Option 1 — 2×4 IDC Female Header (8-pin)  
**Rationale:** This one was basically decided by the course spec. EGR314 requires all boards to use an 8-wire ribbon cable with a 2×4 IDC female header for the daisy chain network, so using anything else would mean my board can't physically connect to my teammates' boards. I have two of these, one for the upstream connection (Connector In) and one for the downstream connection (Connector Out), which matches the layout shown in the class daisy chain diagram.

JST connectors are nice for compact designs but they aren't IDC ribbon-compatible, so the whole team would need custom cables just for my board, which isn't practical. Screw terminals are extremely bulky and also incompatible with ribbon cables. There really wasn't a decision to make here, the 2×4 IDC header is the only option that keeps my board compatible with the rest of the system.

---

## 10. Status & Debug LEDs (Testability)

### Option 1

| Solution | Pros | Cons |
|---|---|---|
| **SMD LED 0805 Green Diffused (ams-OSRAM)**<br>475-LGR971-KN-1CT-ND<br>Standard green SMD LED, 0805 package<br>Price: ~$0.15/each<br>[Product Page](https://www.digikey.com/en/products/detail/ams-osram-usa-inc/LG-R971-KN-1-0-20-R18/1227925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)<br>[Datasheet](https://look.ams-osram.com/m/2da6f2ceeebf8fac/original/LG-R971.pdf) | - Small 0805 footprint — easy to hand solder<br>- Standard current requirements (10–20mA) work with 220Ω resistor at 3.3V<br>- Bright enough for lab visibility<br>- Low cost per unit | - Only one color — less informative for multi-state debug |

### Option 2

| Solution | Pros | Cons |
|---|---|---|
| **RGB SMD LED (Common Cathode)**<br>Price: ~$0.50–$1.00/each | - Multiple colors allow distinct status indication<br>- Single LED replaces 3 status LEDs | - Requires 3 GPIO pins per LED<br>- More complex firmware<br>- Higher cost |
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

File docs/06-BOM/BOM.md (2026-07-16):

---
title: Bill of Materials
tags:
- EGR314 
- Team 302 
---

# Bill of Materials

## Overview

This Bill of Materials (BOM) lists every electronic component required for Mihir Patel’s ESP32-S3 Vision & Wireless Communication Subsystem for the R6 Recon Amphibot (Team 302, EGR314 Spring 2026).

It includes active components, passives, connectors, protection devices, and interface hardware required for PCB fabrication and subsystem integration into the UART daisy-chain architecture.

All components are documented with manufacturer information, part numbers, supplier details, datasheet links, and schematic reference designators to ensure full traceability and verification compliance.

Spare quantities are included where necessary to ensure reliability during assembly, soldering, and system integration testing.

---

## Bill of Materials  

*Table 01: Items below represent the complete BOM associated with this subsystem.*

### Bill of Materials — ESP32-S3 Vision & Wireless Subsystem (Team 302)

| **Part Name / Description** | **Qty** | **Unit Cost** | **Total Cost** | **Manufacturer** | **Manufacturer #** | **Vendor / Source** | **Datasheet / Product Link** | **Reference** |
|:---|:---:|:---:|:---:|:---:|:---:|:---:|:---:|:---:|
| ESP32-S3-WROOM-1-N8R8 (WiFi + BT, 8MB Flash, 8MB PSRAM, PCB Antenna) | 1 | $6.13 | $6.13 | Espressif Systems | ESP32-S3-WROOM-1-N8R8 | Digi-Key | [Datasheet](https://documentation.espressif.com/esp32-s3-wroom-1_wroom-1u_datasheet_en.pdf) | U2 |
| 3.3V 2A Buck Regulator (TSOT23-6, SMD) | 1 | $0.71 | $0.71 | Diodes Inc. | AP63203WU-7 | Digi-Key | [Datasheet](https://www.diodes.com/assets/Datasheets/AP63200-AP63201-AP63203-AP63205.pdf) | U1 |
| OV5640 Camera Breakout (5MP, DVP Interface) | 1 | $17.50 | $17.50 | Adafruit | 5841 | Digi-Key | [Datasheet](https://www.adafruit.com/product/5841) | J6 (Daughterboard) |
| Micro USB Type-B Vertical THT Connector | 1 | $0.78 | $0.78 | GCT | USB3131-30-0230-A | Digi-Key | [Datasheet](https://gct.co/files/specs/usb3131-spec.pdf) | J1 |
| 2.1mm x 5.5mm Barrel Jack (THT) | 1 | $0.59 | $0.59 | Same Sky (CUI) | PJ-102A | Digi-Key | [Datasheet](https://www.sameskydevices.com/product/resource/pj-102a.pdf) | J2 |
| Schottky Diode 40V 3A (SMC SMD) | 4 | $0.70 | $2.80 | onsemi | MBRS340T3G | Digi-Key | [Datasheet](https://www.onsemi.com/pdf/datasheet/mbrs340t3-d.pdf) | D4, D8 |
| Polyfuse PTC 2.6A Hold 16V (1812 SMD) | 3 | $4.6 | $13.80 | Littelfuse | 1812L260/16MR | Digi-Key | [Datasheet](https://www.littelfuse.com/assetdocs/littelfuse-fuse-154-series-data-sheet) | F1 |
| Fixed Inductor 6.8µH 285mA 1.2Ω (1812 SMD) | 2 | $0.28 | $0.56 | Bourns | PM1812-6R8J-RC | Digi-Key | [Datasheet](https://www.bourns.com/docs/Product-Datasheets/pm1812_series.pdf) | L1 |
| 22µF 25V X5R Ceramic Capacitor (1812 SMD) | 2 | $1.09 | $2.18 | TDK | C4532X5R1E226M250KA | Digi-Key | [Datasheet](https://product.tdk.com/system/files/dam/doc/product/capacitor/ceramic/mlcc/catalog/mlcc_commercial_general_en.pdf) | C5, C6 |
| 10µF 25V X5R Ceramic Capacitor (1812 SMD) | 3 | $1.12 | $3.36 | TDK | C4532X5R1E106M250KA | Digi-Key | [Datasheet](https://product.tdk.com/system/files/dam/doc/product/capacitor/ceramic/mlcc/catalog/mlcc_commercial_general_en.pdf) | C2, C7, C9 |
| 0.1µF 630V X5R Ceramic Capacitor (1812 SMD) | 4 | $0.77 | $3.08 | TDK | C4532X5R2J104K230KA | Digi-Key | [Datasheet](https://product.tdk.com/system/files/dam/doc/product/capacitor/ceramic/mlcc/catalog/mlcc_commercial_general_en.pdf) | C1, C3, C4, C8 |
| 10kΩ 1% 1W Resistor (1812 SMD) | 4 | $0.36 | $1.44 | KOA Speer | WK73R2JTTE1002F | Digi-Key | [Datasheet](https://www.koaspeer.com/pdfs/WK73R.pdf) | R1, R5, R11, R12 |
| 220Ω 1% 1W Resistor (1812 SMD) | 5 | $0.37 | $1.85 | Yageo | RC1218FK-07220RL | Digi-Key | [Datasheet](https://yageogroup.com/content/datasheet/asset/file/PYU-RC_GROUP_51_ROHS_L) | R2, R3, R7, R8, R9 |
| 470Ω 1% 1W Resistor (1812 SMD) | 2 | $0.22 | $0.44 | Yageo | RC1218FK-07470RL | Digi-Key | [Datasheet](https://yageogroup.com/content/datasheet/asset/file/PYU-RC_GROUP_51_ROHS_L) | R4, R6 |
| Green LED Diffused 0805 SMD | 5 | $0.15 | $0.75 | ams-OSRAM | LG R971-KN-1-0-20-R18 | Digi-Key | [Datasheet](https://look.ams-osram.com/m/2da6f2ceeebf8fac/original/LG-R971.pdf) | D2–D7 |
| Tactile Switch SPST-NO SMD | 2 | $0.22 | $0.44 | CTS | 222AMVBAR | Digi-Key | [Datasheet](https://www.ctscorp.com/Files/DataSheets/Switches/Tactile-Switches/CTS-Switches-Tactile-222A-Series-Datasheet.pdf) | SW1, SW2 |
| Shunt Jumper 1.27mm Pitch | 4 | $0.16 | $0.64 | Adam Tech | HMSC-G | Digi-Key | [Datasheet](https://app.adam-tech.com/products/download/data_sheet/203317/hmsc-g-data-sheet.pdf) | J6 (Jumper) |
| 1×2 Pin Header 2.54mm THT | 1 | $0.00 | $0.00 | Various | PinHeader_1x02_2.54mm | Peralta | — | J4 |
| 2×4 Pin Header 2.54mm THT | 4 | $0.00 | $0.00 | Various | PinHeader_2x04_2.54mm | Peralta | — | J5, J7, J8, J9 |
| 2×9 Pin Header 2.54mm THT (Camera Connector) | 1 | $0.00 | $0.00 | Various | PinHeader_2x09_2.54mm | Peralta | — | J6 Header |
| Test Point | 8 | $0.00 | $0.00 | Various | Test Point | Peralta | — | T1, T2, T3, T4, T5, T6, T7, T8 |
| **Estimated Total Cost** |  |  | **$57.05** |  |  |  |  |  |
| **Tax** |  |  | **$4.71** |  |  |  |  |  |
| **Shipping Charges** |  |  | **$6.99** |  |  |  |  |  |
| **Tariff** |  |  | **~$1.07** |  |  |  |  |  |
| **Final TOTAL Cost** |  |  | **$69.82** |  |  |  |  |  |

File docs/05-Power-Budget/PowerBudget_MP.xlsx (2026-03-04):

Power Budget - Mihir Patel
Team Number: | Team 302
Project Name: | R6 Recon Amphibot
Team Member Names: | Lakshanand Sugumar, Raunak Singh
Version: | 1B (updated components)
A. List ALL major components (active devices, integrated circuits, etc.) except for power sources, voltage regulators, resistors, capacitors, or passive elements
All Major Components | Component Name | Part Number | Supply Voltage Range | # | Absolute Maximum Current (mA) | Total Current (mA) | Unit
 | ESP32-S3-Wi-Fi Module | ESP32-S3-WROOM-1-N8R8 | 3.3V | 1 | 500 | 500 | mA
 | Camera module (OV5640) | OV5640 | 3.3V | 1 | 250 | 250 | mA
 | Debug LEDs (SMD 0805) | LG-R971-KN-1 | 3.3V | 5 | 20 | 100 | mA
 | Tactile Switches | CTS 222AMVBAR | 3.3V | 2 | 1 | 2 | mA
 | USB VBUS sense/logic | - | 3.3V | 1 | 20 | 20 | mA
 | Misc overhead / margin | - | 3.3V | 1 | 50 | 50 | mA
B. Assign each major component above to ONE power rail below. Try to minimize the number of different power rails in the design. Add additional power rails or change the power rail voltages if needed.
+3.3V Power Rail | Component Name | Part Number | Supply Voltage Range | # | Absolute Maximum Current (mA) | Total Current (mA) | Unit
 | ESP32-S3-Wi-Fi Module | ESP32-S3-WROOM-1-N8R8 | 3.3V | 1 | 500 | 500 | mA
 | Camera moduel (OV5640) | OV5640 | 3.3V | 1 | 250 | 250 | mA
 | Debug LEDs (SMD 0805) | LG-R971-KN-1 | 3.3V | 5 | 20 | 100 | mA
 | Tactile Switches | CTS 222AMVBAR | 3.3V | 2 | 1 | 2 | mA
 | USB VBUS sense/logic | - | 3.3V | 1 | 20 | 20
 | Misc overhead / margin | - | 3.3V | 1 | 50 | 50
 | Subtotal |  |  |  |  | 922 | mA
 | Safety Margin (25%) |  |  |  |  | 25%
 | Total Current Required on +3.3V Rail |  |  |  |  | 1152.5 | mA
c1. Regulator or Source Choice | Buck Switching Regulator 3.3V (2A) | AP63203WU-7 | +3.8V - 32V | 1 | 2000 | 2000 | mA
 | Total Remaining Current Available on 3.3V Rail |  |  |  |  | 847.5 | mA
C. For each power rail above, select a specific voltage regulator using the same process as for major component selection. Confirm that the Total Remaining Current Available on each rail above is not negative.
Power Rail | Component Name | Part Number | Supply Voltage Range | # | Absolute Maximum Current (mA) | Total Current (mA) | Unit
3.3V Power Rail | Buck Regulator (1.5A variant) | AP63203WU-7 | +3.8V - 32V | 1 | 2000 | 2000 | mA
D. Select a specific external power source (wall supply or battery) for your system, and confirm that it can supply all of the regulators for all of the power rails simultaneously. If you need multiple power sources, list each separately below and indicate which regulators will be connected to each supply. Confirm that the Total Remaining Current Available on each power source below is not negative.
External Power Source 1 | Component Name | Part Number | Supply Voltage Range | Output Voltage | Absolute Maximum Current (mA) | Total Current (mA) | Unit
Power Source 1 Selection | 9V AC-DC Wall Adapter | WSU090-2500 | 100 ~ 240VAC | 9V | 2500 | 2500 | mA
Power Rails Connected to External Power Source 1
 | +3.3V [Buck Regulator (2A variant)] | AP63203WU-7 | +3.8V - 32V | 1 | 2000 | 2000 | mA
 | Total Remaining Current Available on External Power Source 1 |  |  |  |  | 500 | mA
External Power Source 2 | Component Name | Part Number | Supply Voltage Range | Output Voltage | Absolute Maximum Current (mA) | Total Current (mA) | Unit
Power Source 2 Selection | Battery (12V) - Raunak's shared power | B09ZTKTLGW | 12V | 12V | 7000 | 7000 | mA
Power Rails Connected to External Power Source 1
 | +3.3V [Buck Regulator (2A variant)] | AP63203WU-7 | +3.8V - 32V | 1 | 2000 | 2000 | mA
 | Total Remaining Current Available on External Power Source 1 |  |  |  |  | 5000 | mA
Notes
1. External Supply Voltage should be determined by the dropout voltage for the highest-voltage regulator (e.g., +14V for a +12V regulator). The WSU090-2500 outputs 9V DC, which is well above the AP63203WU-7's minimum input voltage of 3.8V, providing adequate dropout margin. 2. The AP63203WU-7 is rated for 2A continuous output current. Total required on the +3.3V rail including 25% safety margin is 1152.5 mA, well within the 2A rating, leaving 847.5 mA of regulator headroom. 3. The ESP32-S3 and OV2640 camera are unlikely to simultaneously draw peak current. In typical operation (MQTT active + camera streaming), total draw remains well under 900 mA. 4. If you have multiple units in your design (e.g., a base unit and remote unit) then you need a separate power budget for each unit. 5. Passive components (resistors, capacitors, inductors) are excluded from this power budget per EGR314 course guidelines.

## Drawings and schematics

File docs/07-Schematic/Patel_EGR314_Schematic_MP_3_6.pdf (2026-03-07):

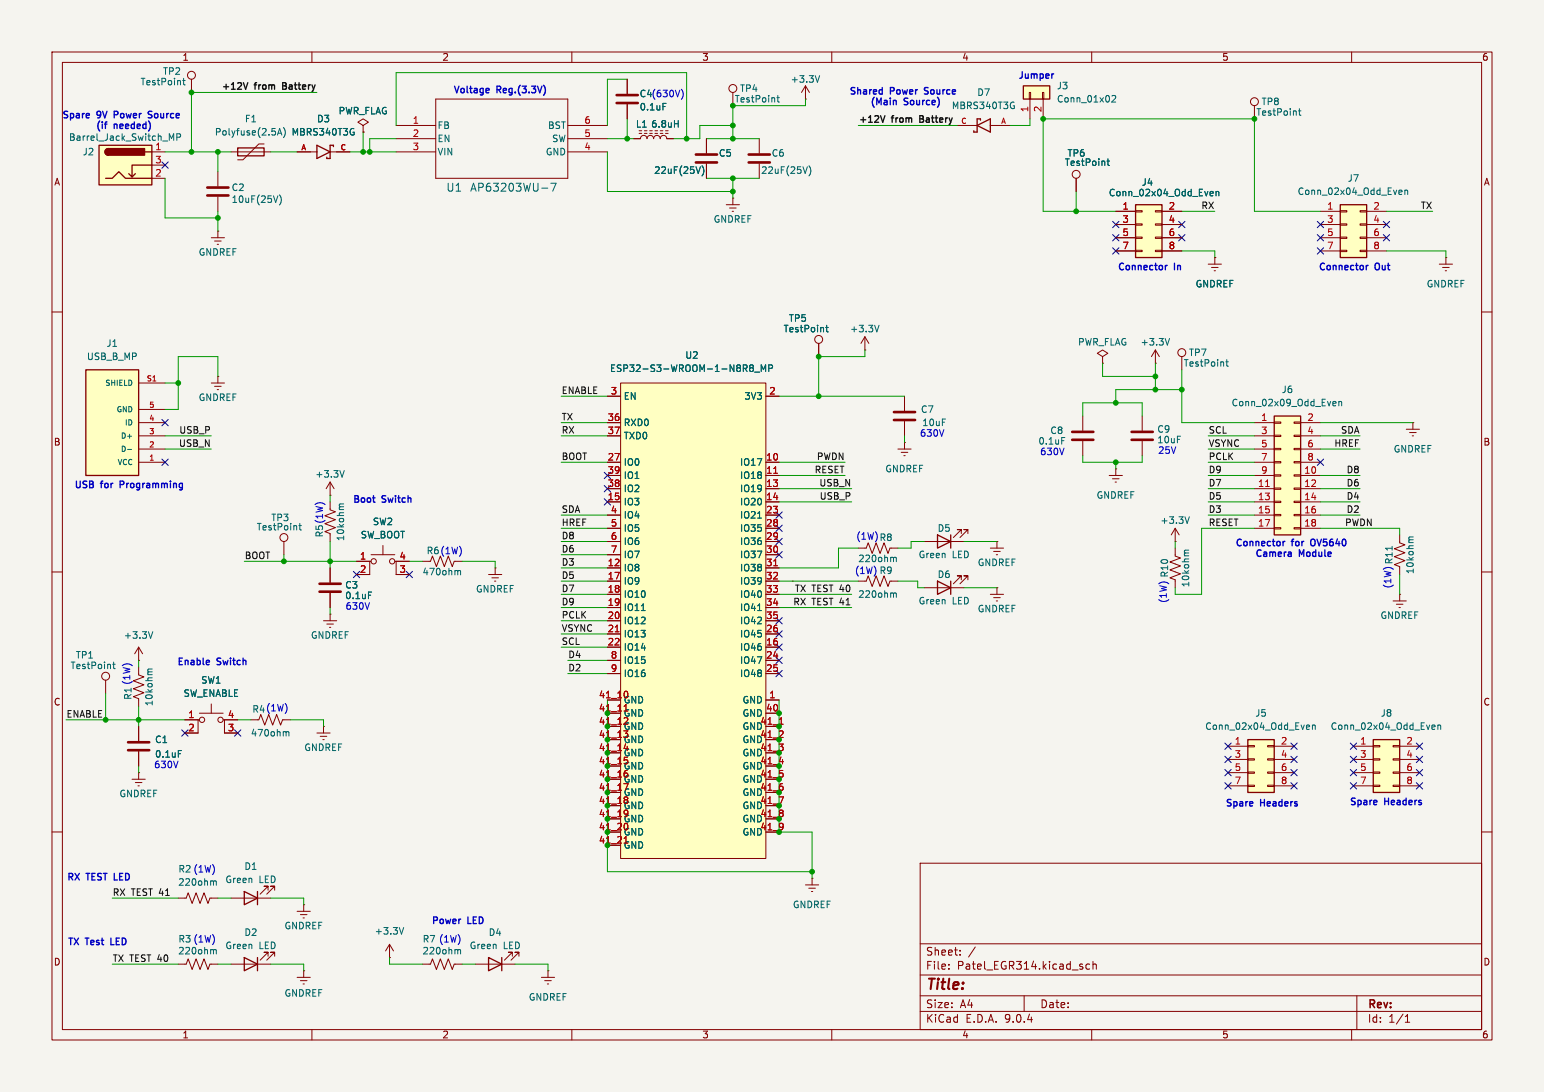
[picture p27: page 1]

TX RX TEST 41 TX TEST 40 ENABLE

Id: 1/1 Title: File: Patel_EGR314.kicad_sch Sheet: /

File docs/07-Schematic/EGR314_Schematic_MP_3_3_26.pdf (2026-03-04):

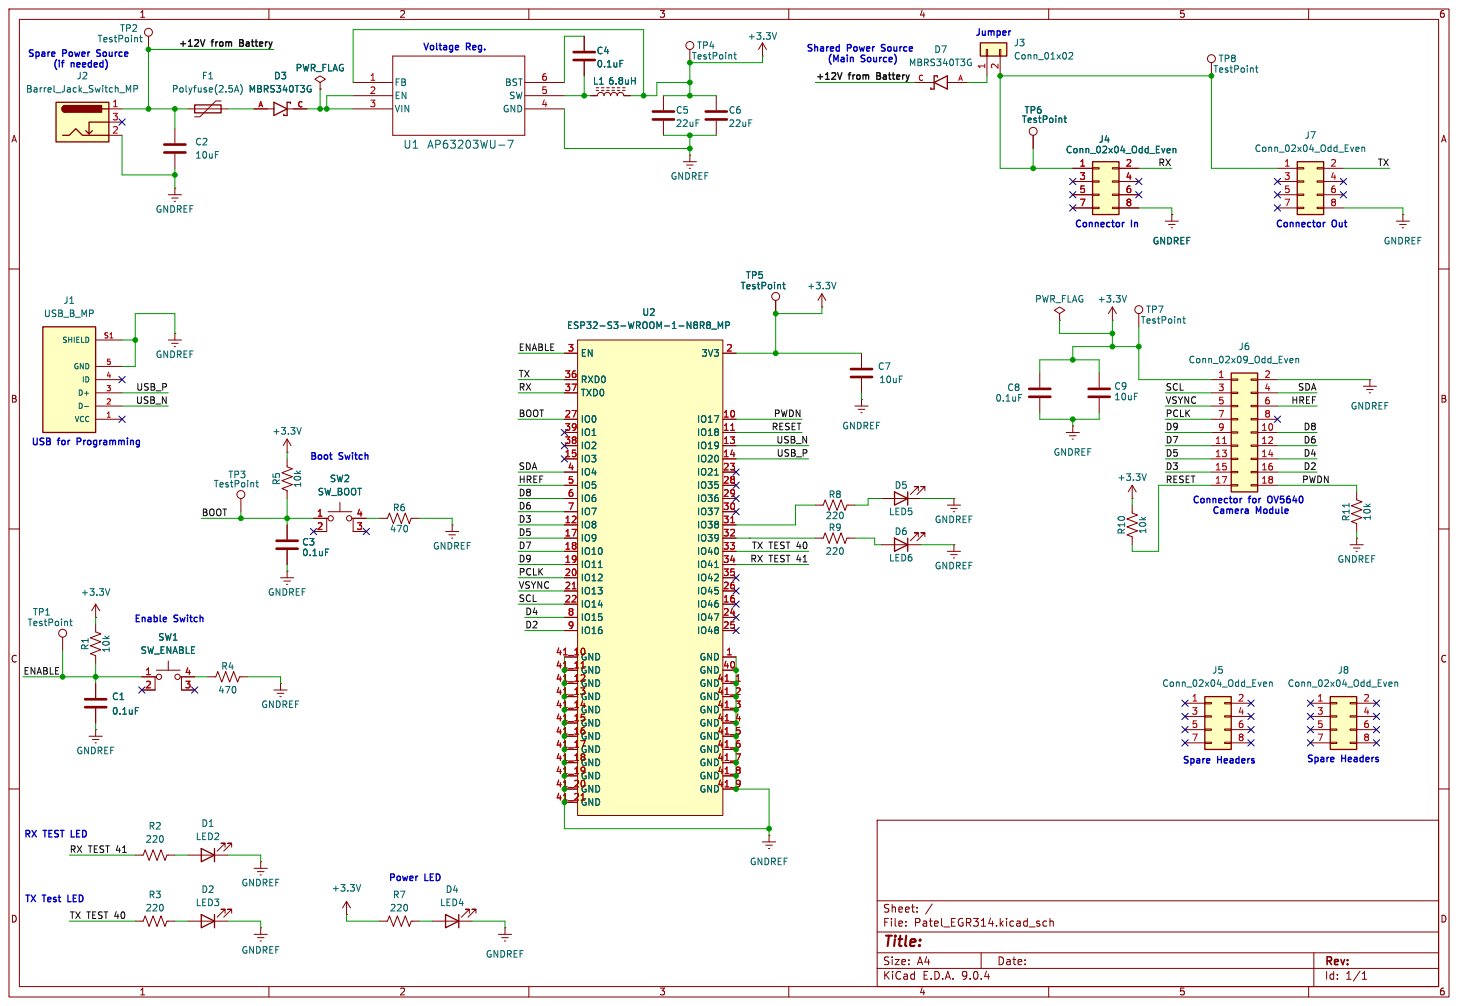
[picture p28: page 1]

TX TEST 40 RX TEST 41 USB_P USB_N

RX TEST 41 Enable Switch
3 SW1 SW_ENABLE GNDREF

Id: 1/1 Title: File: Patel_EGR314.kicad_sch Sheet: /

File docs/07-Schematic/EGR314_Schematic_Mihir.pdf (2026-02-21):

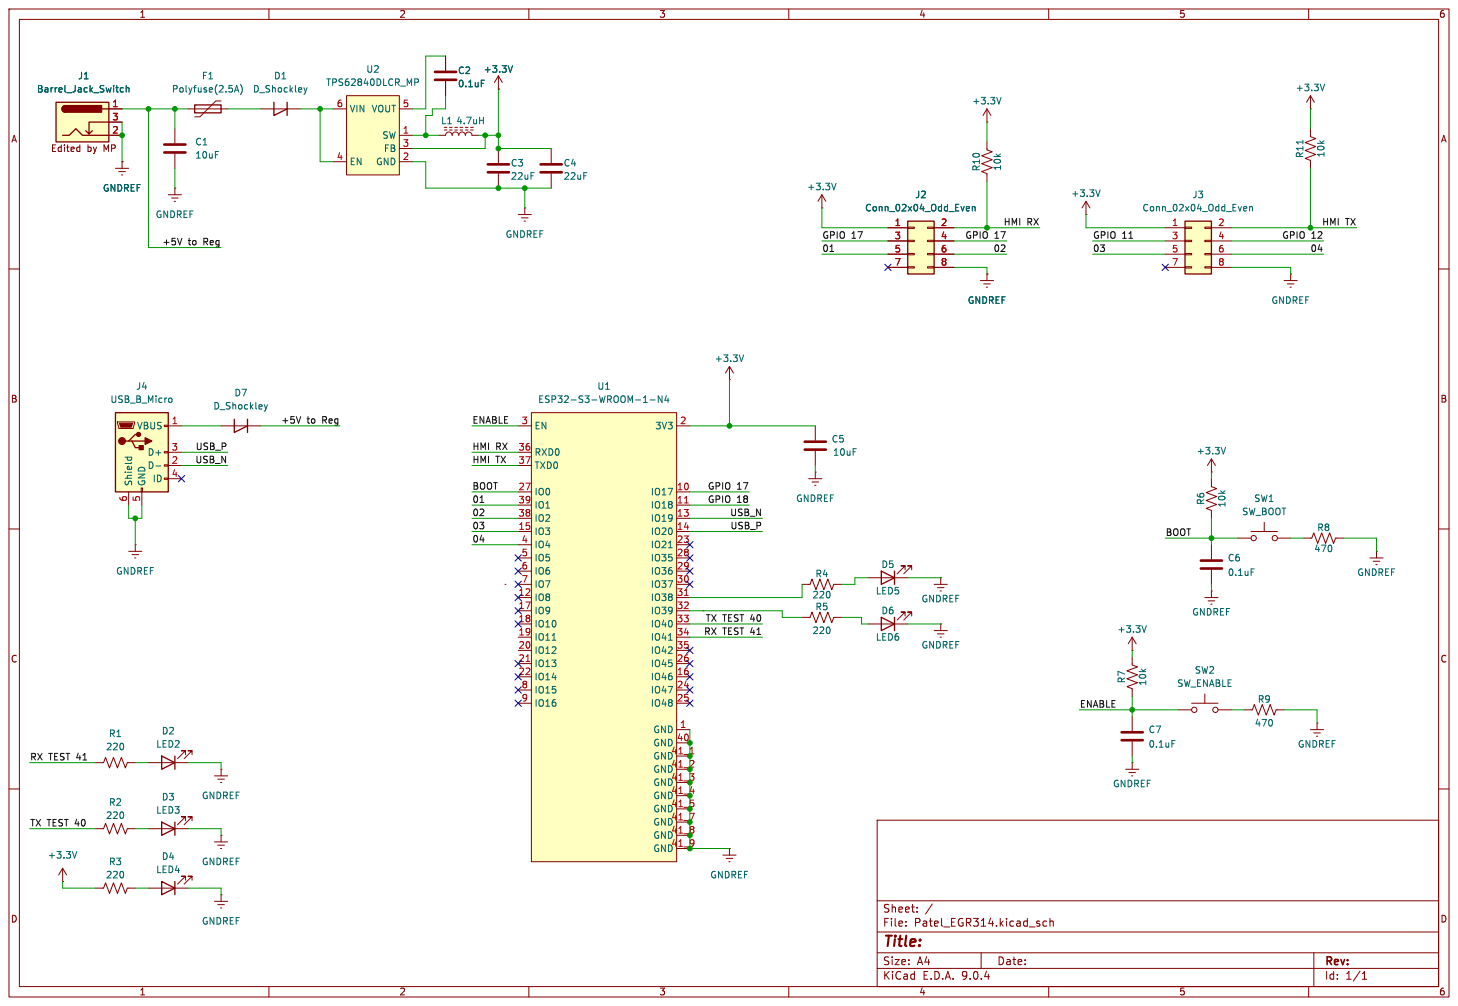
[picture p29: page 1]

BOOT HMI RX HMI TX USB_P

Id: 1/1 Title: File: Patel_EGR314.kicad_sch Sheet: /

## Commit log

2026-02-12 made new sections for power budget and microcontroller selection
2026-02-12 made md files for pcb and power budget
2026-02-12 updated power budget
2026-02-12 change in format in power budget
2026-02-12 link updated of 3.3V switching regulator
2026-02-21 individual schematic update and added
2026-02-24 changed Amp rating of switching regulator
2026-02-24 updated power supply
2026-02-24 added power budget
    [PowerBudget_MP.xlsx]
2026-02-26 updated to N8R8 esp32 version
    [PowerBudget_MP.xlsx]
2026-02-26 updated pin table...
2026-03-03 added BOM page
2026-03-04 updated schematic and component selection part
2026-03-04 updated power budget and microcontroller section
    [PowerBudget_MP-1.xlsx, PowerBudget_MP.xlsx]
2026-03-04 added pcb and schematic files
    [Patel_EGR314-B_Cu.gbr, Patel_EGR314-B_Mask.gbr, Patel_EGR314-B_Paste.gbr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]
2026-03-05 updated block diagram, removed one jumper as per schematics and updated that shared power is 12V from battery pack
2026-03-07 updated schematic
2026-04-11 updated schematic and pcb images
2026-05-02 final update to website including each and every page
    [PowerBudgetExample.xlsx]
2026-05-04 updated raw and with parts pcb images
